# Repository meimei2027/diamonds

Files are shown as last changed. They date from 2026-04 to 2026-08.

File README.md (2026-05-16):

### Experimental Design
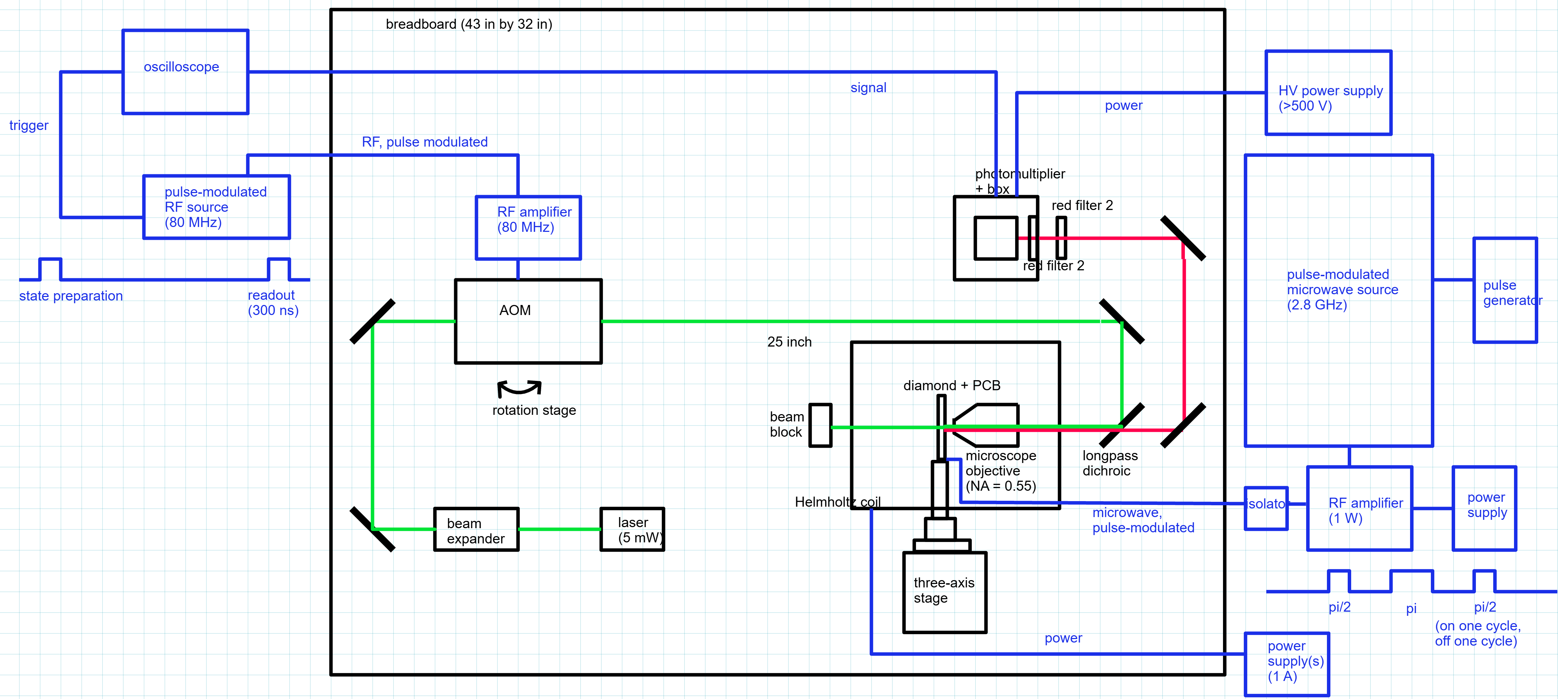
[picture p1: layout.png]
layout

### NV diamond spectrum
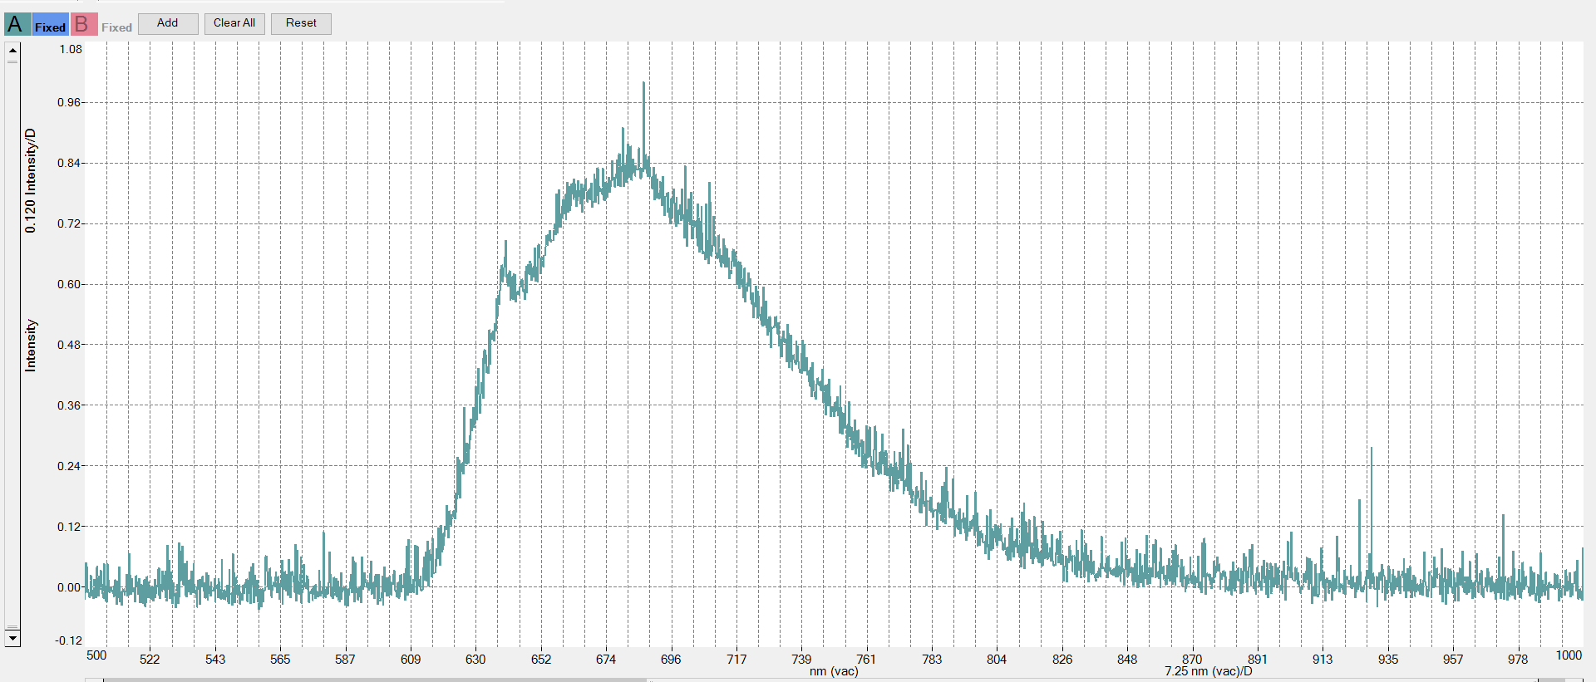
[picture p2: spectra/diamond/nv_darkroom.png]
spectra

Figure obtained using a Thorlabs CCS200 spectrometer with 10 second integration time. 
A fluorescence signal was obtained by directing the 532nm laser onto the diamond, then using a FGL630M longpass filter to isolate the red fluorescence.

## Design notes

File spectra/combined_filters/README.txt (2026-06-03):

All data was collected using a 1Hz on off pulse on a 532nm laser, which was focused onto the diamond using a microscope objective, then filtered out by a DMLP550 dichroric mirror as well. The spectra was taken using a CCS200 thorlabs optical spectrometer, with the lights off.

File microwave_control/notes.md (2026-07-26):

# Instrument gotchas

Quick reference for things that aren't obvious from the driver code alone.
See `CLAUDE.md` for the full investigation history behind each of these.

## HP8673H signal generator

- **Pre-SCPI, mnemonic ASCII commands** (e.g. `FR3000000000HZ`), not SCPI
  strings. Full command table is Table 3-7 in the HP 8673C/D manual (same
  codes across the whole 8673A/B/C/D/E/G/H family).
- **Frequency resolution is 1 kHz** between 2-4 GHz on our unit (matches the
  manual's spec table). Anything finer gets silently floored.
- **Sweep-start settling**: the first point of any sweep involves a large
  jump from wherever the generator was previously sitting. AUTO PEAK
  re-leveling triggers automatically on frequency changes >50 MHz and takes
  much longer to settle than normal step-to-step timing. Without an extra
  delay after that initial jump, the first few points of a sweep read
  anomalously low -- easy to mistake for a real resonance dip, especially
  since it appears at whatever frequency the sweep happens to start at.
  `frequency_sweep()` handles this via `initial_settle_s` (default 1.0 s,
  applied once before the per-step loop begins) -- don't set it to 0 unless
  you really know what you're doing.
- **GPIB bus number isn't stable.** Has shown up as both `GPIB0::19::INSTR`
  and `GPIB1::19::INSTR` depending on adapter enumeration order. Always
  `pyvisa.ResourceManager().list_resources()` before assuming an address.

## E4403B spectrum analyzer

- **Trace averaging** is `AVER:STATE ON` + `AVER:COUNT n`, not
  `DISP:WIND:TRAC1:MODE AVER` (undefined header on this firmware).
  `TRAC1:MODE` only accepts `WRITE|MAXHOLD|MINHOLD|VIEW|BLANK`.
- **`TRAC1:MODE BLANK` poisons subsequent reads**: `TRACE:DATA?` returns a
  flat sentinel (`400.0` everywhere) until you set the mode back to
  `WRITE`. Looks like a driver bug, is actually leftover instrument state.
- **Amplitude calibration can genuinely drift out of spec.** We hit a real
  fault where readings were 20-37 dB too high, worse at some frequencies
  than others. All of the instrument's own settings (attenuation, preamp,
  units, offset) checked out normal -- it was a real internal cal fault, not
  a settings mistake. **Fix: front panel Align Now -> RF (not Align Now ->
  All), with a cable connected to the input.** After a real cal fault, don't
  trust *any* absolute dBm reading until this has been done and reverified
  with a known source.
- **Even when calibration is healthy, expect a small residual offset** from
  ordinary cable loss (we consistently see ~-4.4 to -4.5 dB direct
  generator-to-analyzer). This is normal, not a fault -- re-measure if the
  cable changes.
- **Noise floor is RBW/attenuation dependent, and auto-RBW isn't always what
  you expect.** Measured ~-64.3 dBm median at 1 MHz RBW / 10 dB attenuation,
  but the analyzer's auto-coupling picked 3 MHz RBW for the same 500 MHz
  span on one occasion, giving a very different-looking floor. Set `BAND`
  explicitly if you need a result comparable to a previous measurement.
- **"Query UNTERMINATED" / frozen-looking display**: caused by an
  exploratory SCPI query that isn't valid on this firmware timing out on
  the controller side without ever reading the response, leaving the
  instrument's output queue in a pending state. Fix: drain any stale
  response (`inst.read()` in a loop until it raises), then `inst.clear()`
  (GPIB device clear) followed by `*CLS`.

## General

- **Two GPIB-USB adapters share a USB hub**, causing intermittent
  `VI_ERROR_CONN_LOST`. `visa_retry.py`'s `call_with_reconnect()` retries
  automatically (up to 3x) and is already wired into both driver classes'
  `write`/`query`/`get_trace` -- but a hard crash with this error mid-sweep
  is usually just this, and a plain retry of the same sweep works.
- **Always verify a new physical setup before trusting a measurement.**
  Sweep the generator's power over a wide range at a fixed frequency and
  confirm the analyzer's reading actually tracks it, then confirm it drops
  further with RF off. A disconnected/floating analyzer input on this
  E4403B reads a flat, power-independent, RF-state-independent level
  (~-45 to -48 dBm across 2-3 GHz) that looks deceptively like a real, if
  boring, signal.
- **Step size for finding an unknown resonance should track its FWHM, not
  be a fixed default.** Rule of thumb: step <= FWHM/5 to reliably identify
  a dip and get a rough shape; step <= FWHM/2 only guarantees detection,
  not an accurate depth. `resonance_sweep.py`'s default coarse step
  (6.7 MHz) assumes Q ~75 -- retune it if you have reason to expect a much
  higher-Q (narrower) resonance.
- **A coupler's directivity sets a hard floor on reflection measurements.**
  Our ZABDC20-322H-S+ has ~13 dB directivity in this band -- if whatever
  you're measuring reflects less than that relative to a matched load, you
  won't be able to tell it apart from the coupler's own leakage.

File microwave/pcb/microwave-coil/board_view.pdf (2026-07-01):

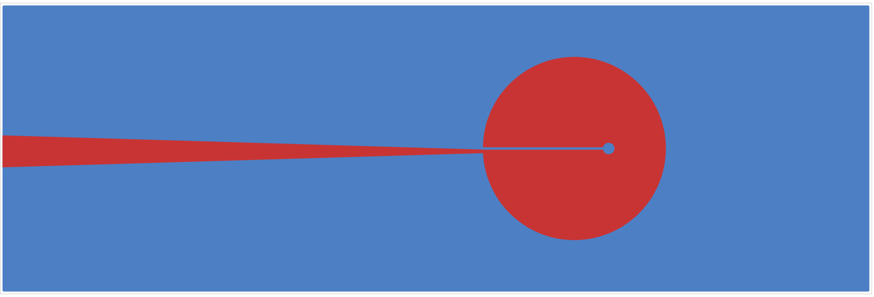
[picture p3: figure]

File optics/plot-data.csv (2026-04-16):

x | y
3.199253183930214e-7 | 0.04125478376005761
3.4184309641687807e-7 | 0.0519011615553862
3.5778330552594773e-7 | 0.06787075363134606
3.68742194537876e-7 | 0.08650190208168791
3.806974083763627e-7 | 0.10114071597045689
3.936487950235825e-7 | 0.12642585688862082
4.056040088620691e-7 | 0.1450570561048964
4.1556664905635175e-7 | 0.16102664818085627
4.2552928925063434e-7 | 0.17699618949088242
4.374844270802084e-7 | 0.1929657815668423
4.47447067274491e-7 | 0.21026615182999314
4.6239102756591485e-7 | 0.2302281292334595
4.76338739039693e-7 | 0.25019010663692604
4.88293876869267e-7 | 0.2688213058532015
4.96264019428258e-7 | 0.2821292907888458
5.11207979719682e-7 | 0.2954372757244902
5.211706199139646e-7 | 0.31539925312795664
5.34122082570097e-7 | 0.3326996233911075
5.510585404968124e-7 | 0.34866921546706736
5.620174295087406e-7 | 0.36064642221552073
5.749688921648731e-7 | 0.373954407151165
5.919053500915884e-7 | 0.3952471627418224
6.058530615653664e-7 | 0.40456276234996014
6.168119505772948e-7 | 0.421863132613111
6.287671644157816e-7 | 0.4311787322212487
6.367372309658602e-7 | 0.43916350287626177
6.466998711601426e-7 | 0.44581749534408394
6.556662625367795e-7 | 0.4551330949522217
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

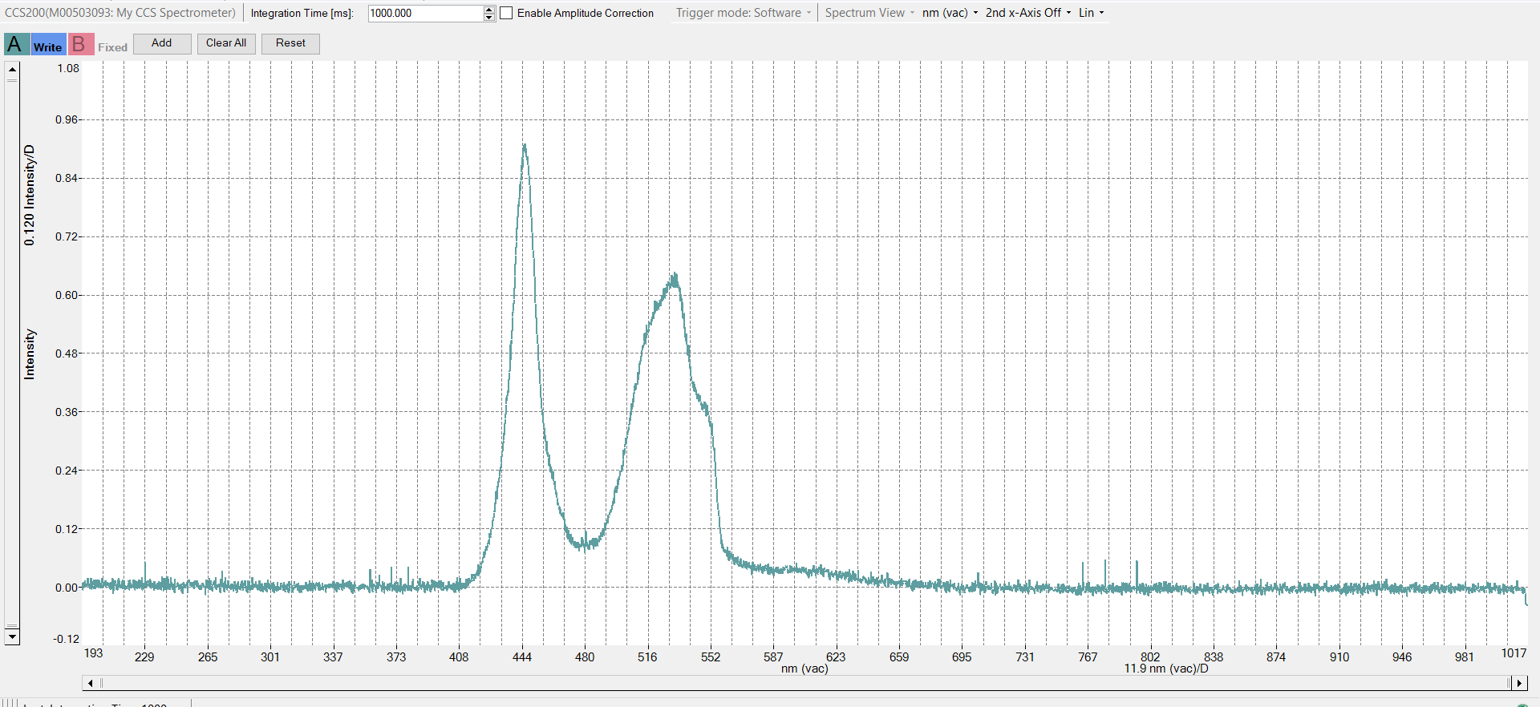
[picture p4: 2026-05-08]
spectra/filters/darkroom_white_light_DMLP550.png

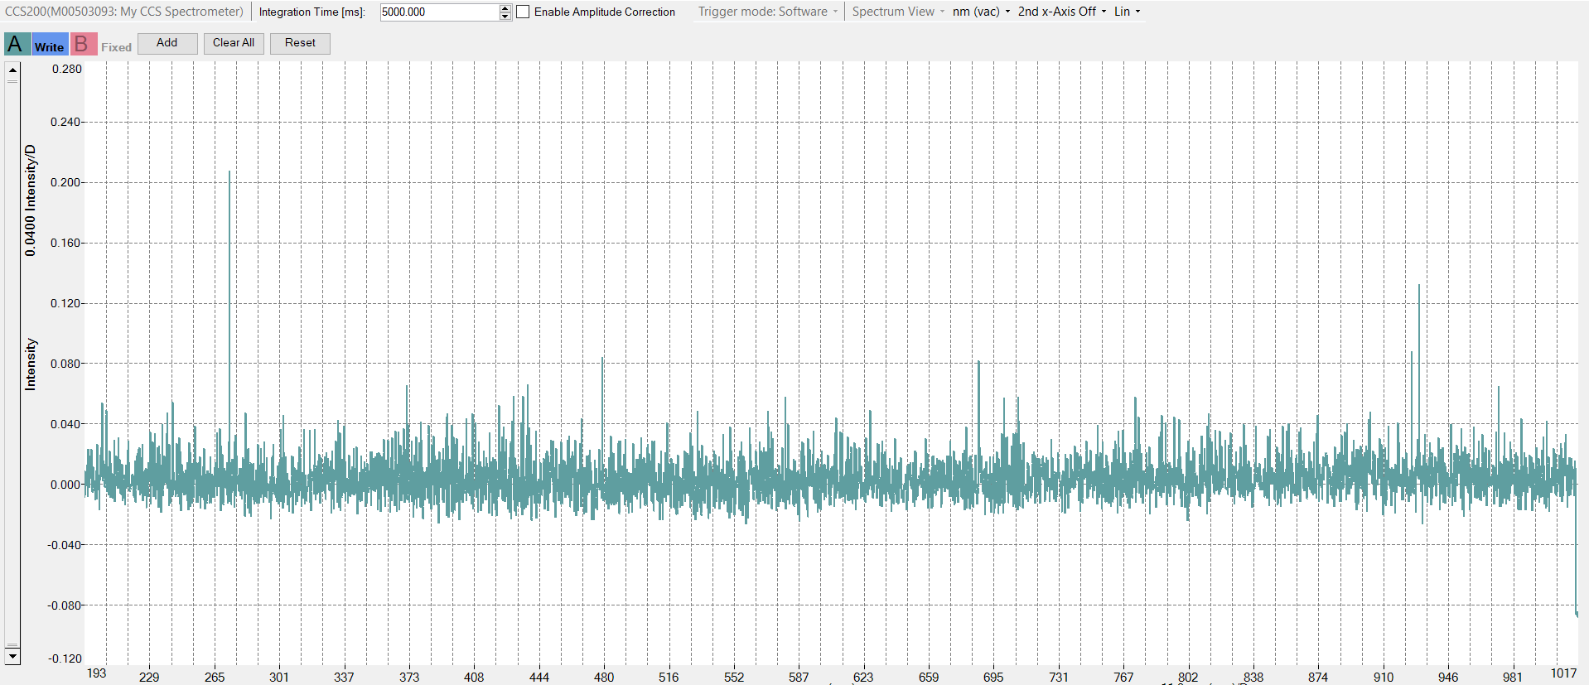
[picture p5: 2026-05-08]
spectra/darkroom_background.png

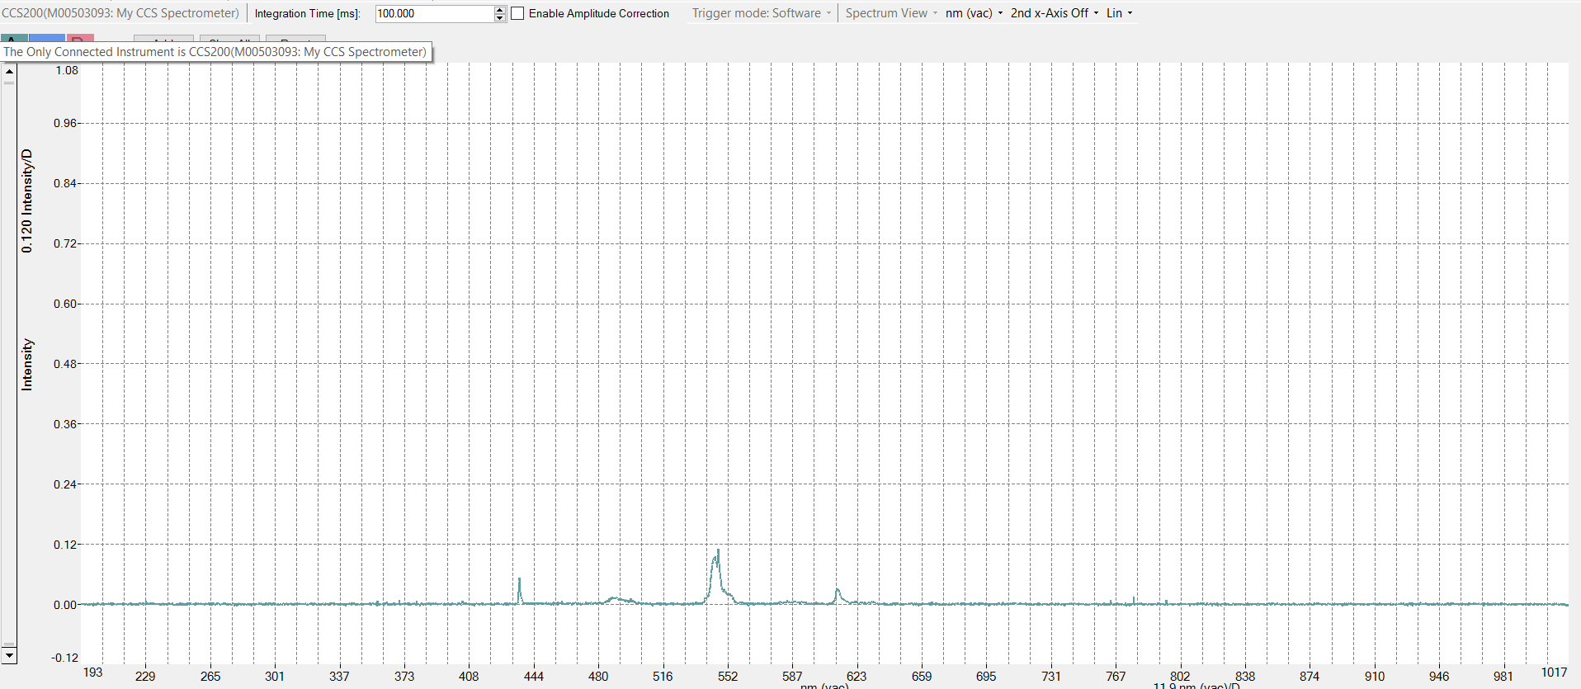
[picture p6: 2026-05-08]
spectra/filters/laser_DMLP550.png

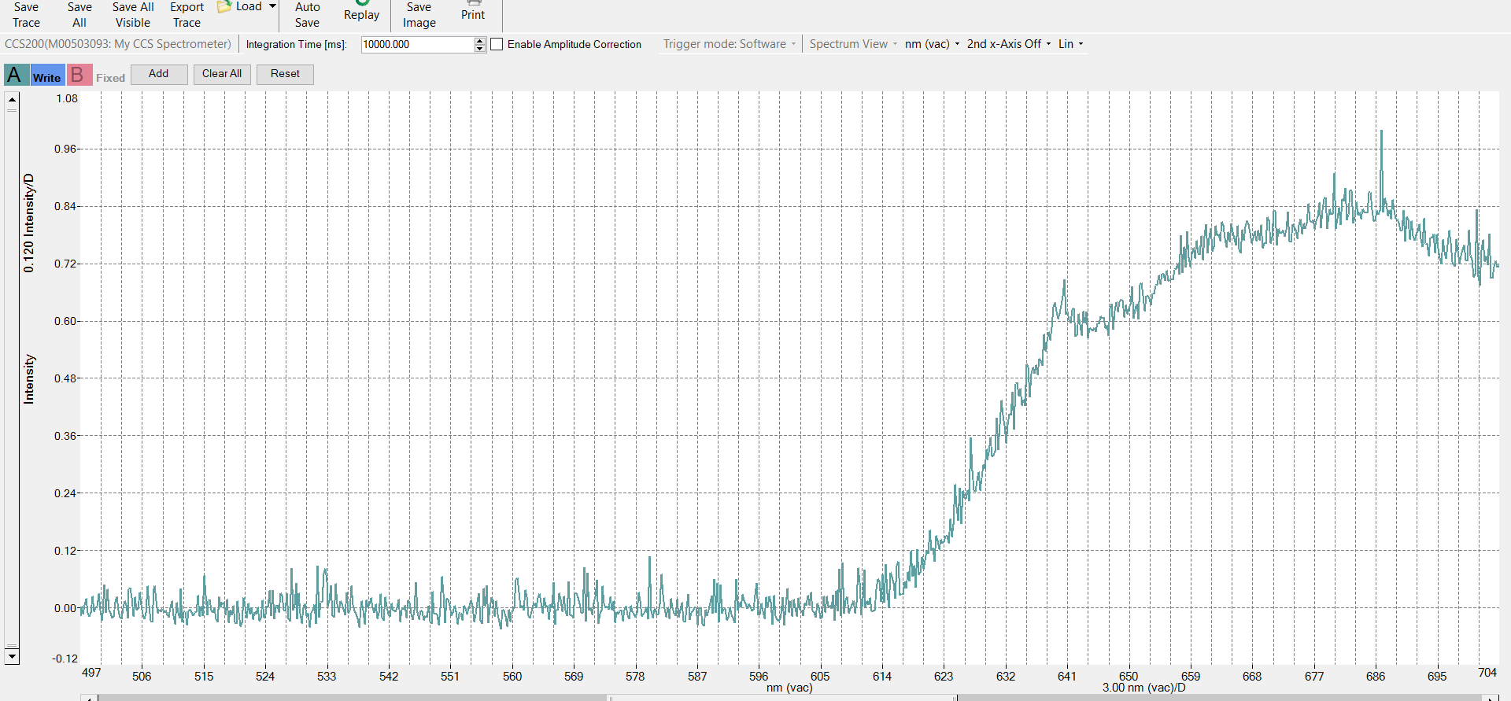
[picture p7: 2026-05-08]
spectra/diamond/nv_darkroom_3.png

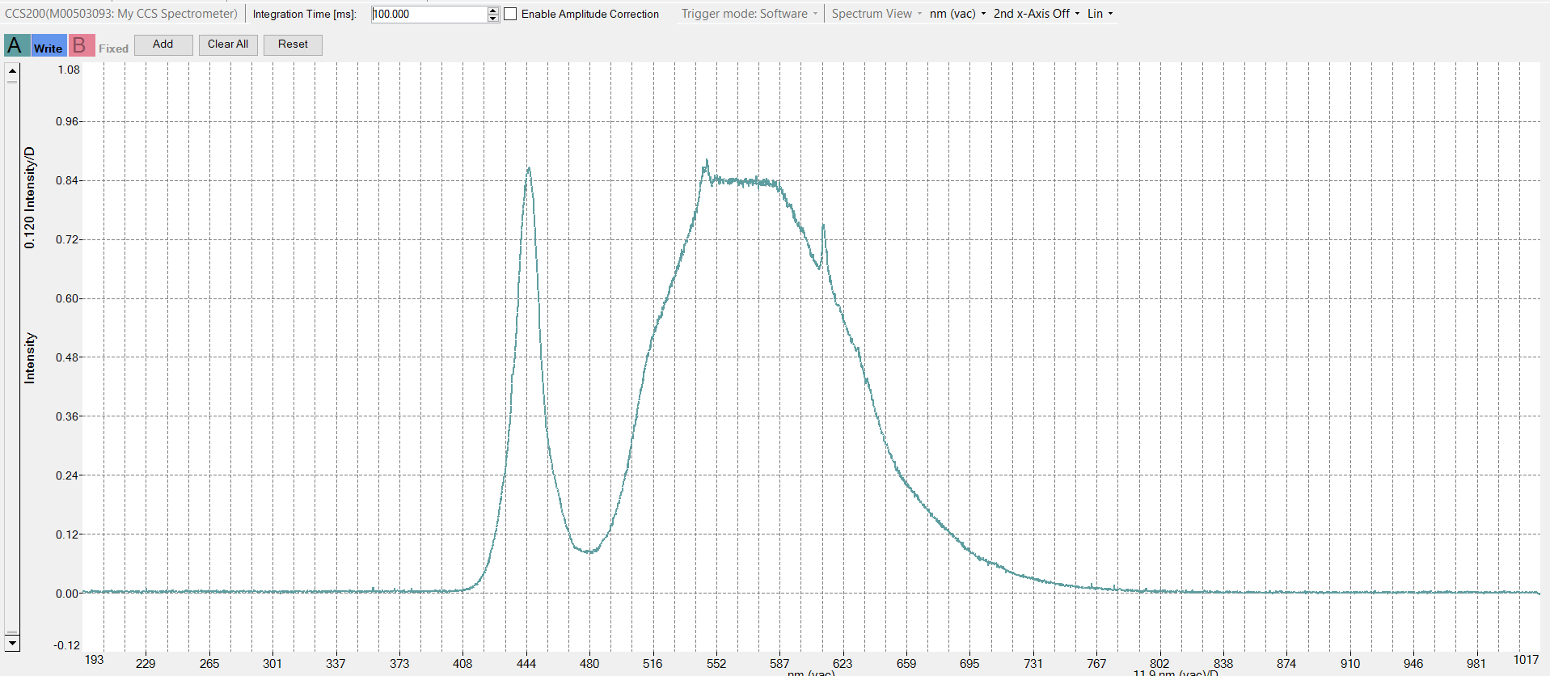
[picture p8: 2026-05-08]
spectra/filters/white_light_no_filter.png

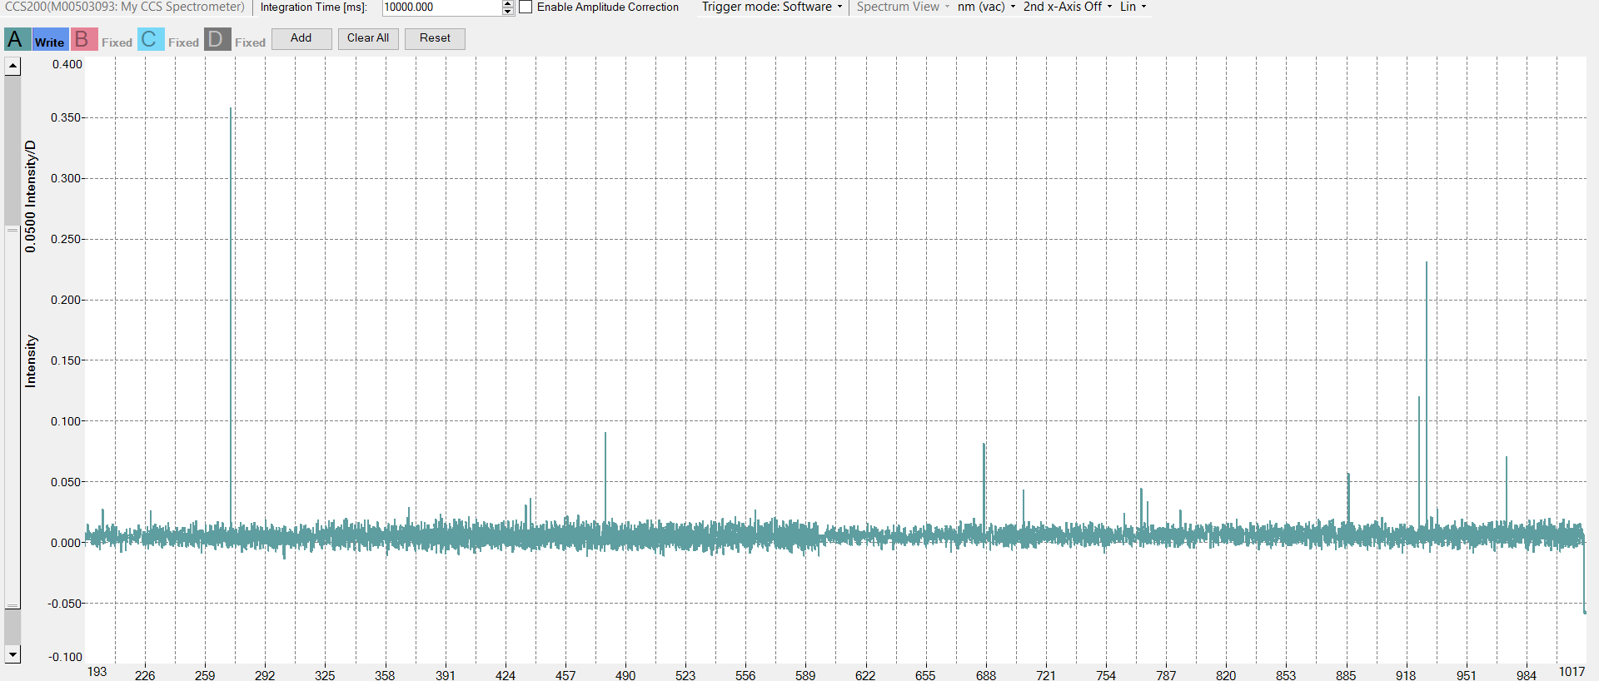
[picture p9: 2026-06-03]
spectra/combined_filters/capped_optical_cable.png

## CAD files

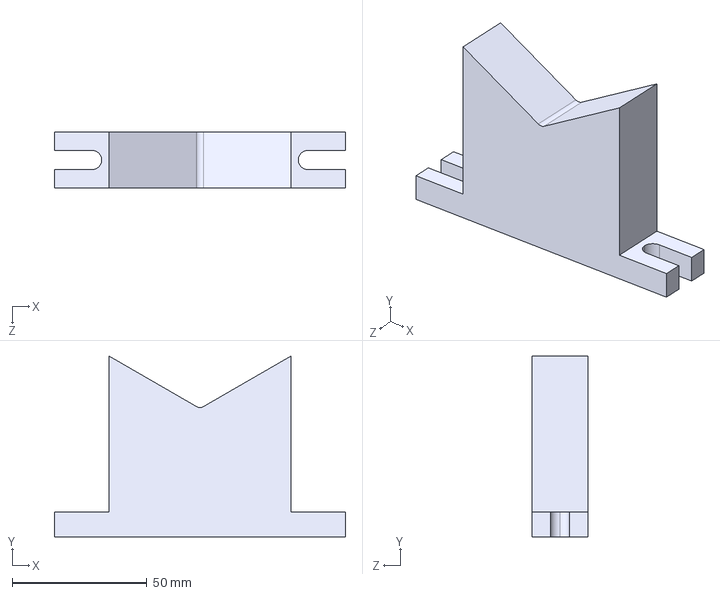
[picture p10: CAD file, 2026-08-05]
drawings/coil-holder.STEP
108.1 x 67.1 x 20.8 mm

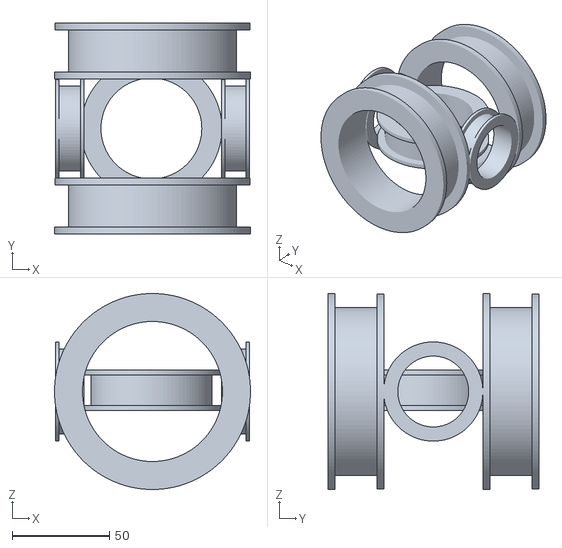
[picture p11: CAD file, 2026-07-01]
presentation_plot/Helmholtz Coils.stl
100.8 x 108.6 x 100.8

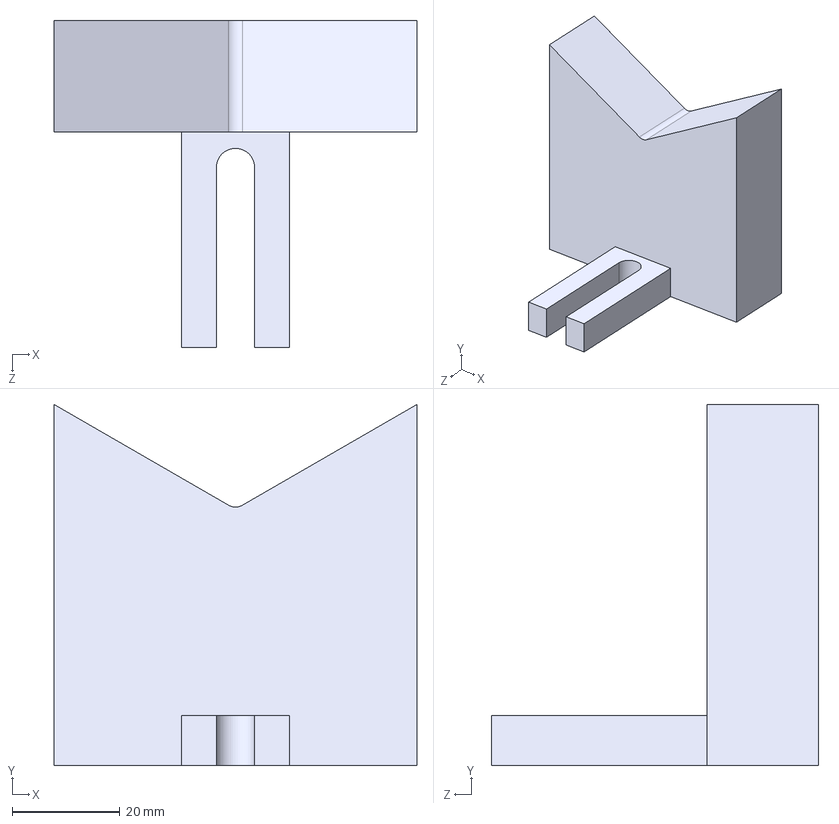
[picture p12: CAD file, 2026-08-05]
drawings/coil-holder-2.STEP
67.5 x 67.1 x 60.8 mm

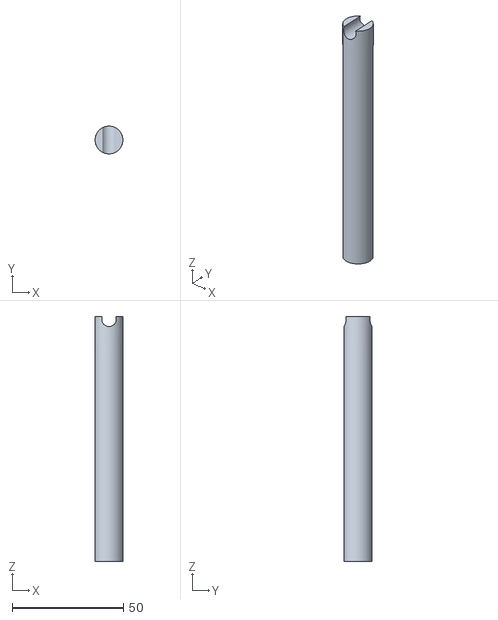
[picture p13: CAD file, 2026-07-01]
presentation_plot/CopperTubeMount.stl
12.5 x 12.5 x 110.0

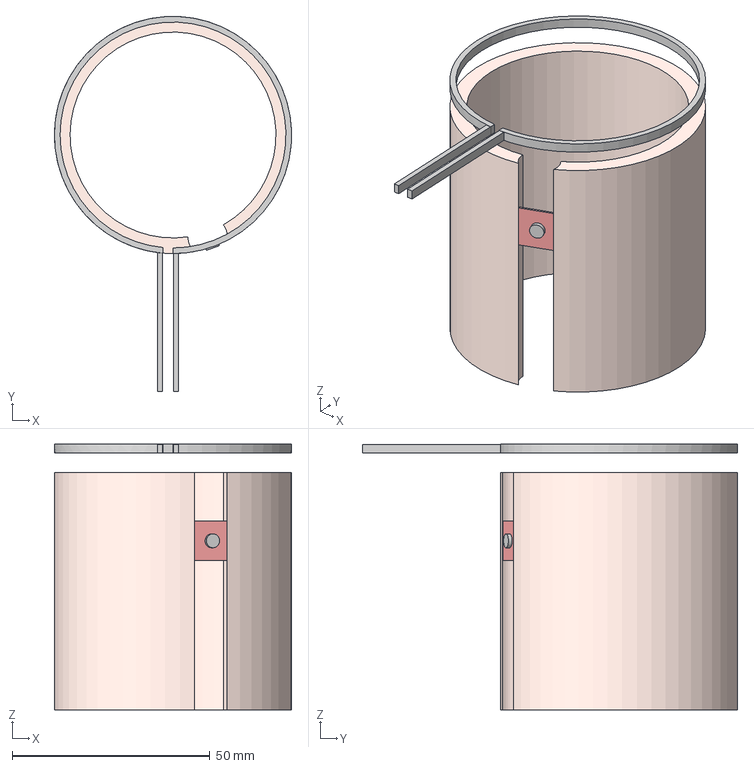
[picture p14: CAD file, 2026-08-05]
drawings/LoopGapResonator.step
60.0 x 94.9 x 67.2 mm

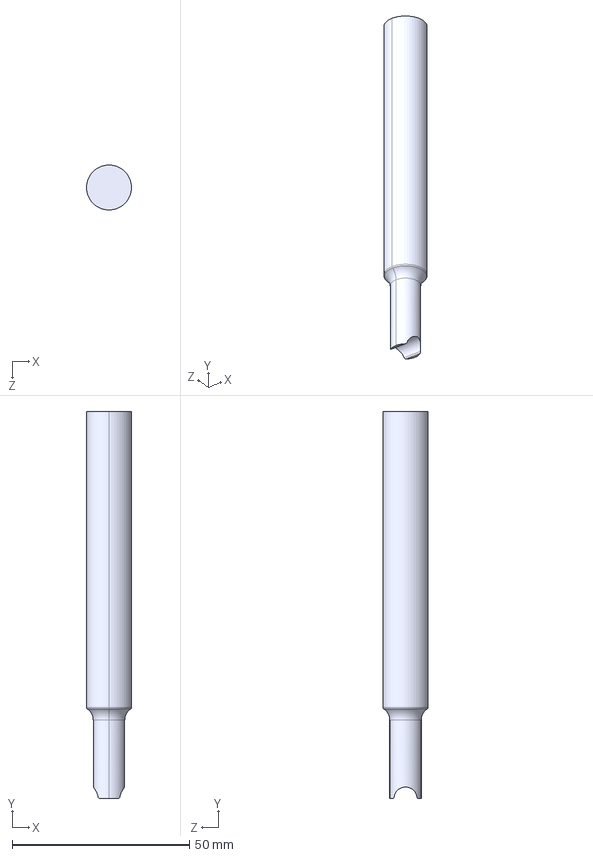
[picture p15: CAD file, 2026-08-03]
drawings/copper-tube-mount.STEP
12.7 x 109.2 x 12.7 mm

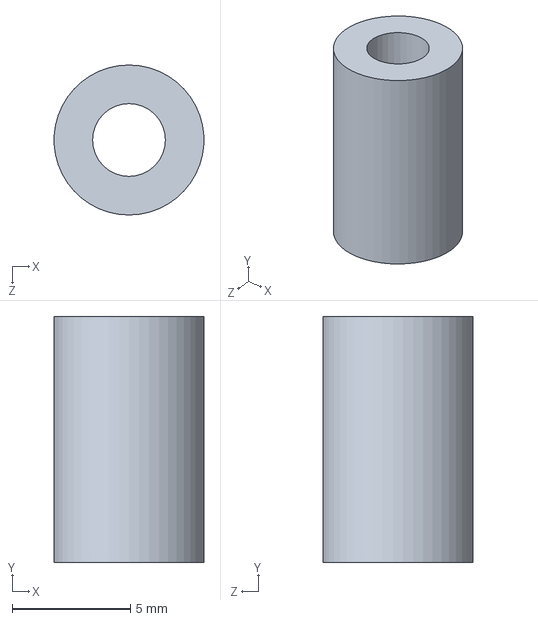
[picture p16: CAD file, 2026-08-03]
drawings/copper-tube.SLDPRT
6.34 x 10.4 x 6.35 mm

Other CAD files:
drawings/coil-holder-2.SLDPRT
drawings/coil-holder.SLDPRT

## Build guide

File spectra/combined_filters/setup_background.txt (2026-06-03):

1.933779755e+02,-1.095455792e-02
1.935834351e+02,-2.785268798e-02
1.937889099e+02,-4.011977580e-04
1.939943848e+02,-1.736309379e-02
1.941998901e+02,-5.757586099e-03
1.944053955e+02,-1.669354551e-02
1.946109161e+02,1.436075382e-02
1.948164520e+02,-9.009678848e-03
1.950220032e+02,1.002462953e-02
1.952275696e+02,-2.109343745e-02
1.954331360e+02,4.104704782e-02
1.956387177e+02,4.694544896e-02
1.958443298e+02,2.548801340e-02
1.960499420e+02,-2.000940591e-02
1.962555695e+02,1.598680019e-02
1.964611969e+02,4.598895088e-02
1.966668549e+02,2.436412731e-03
1.968725128e+02,3.718917072e-02
1.970782013e+02,5.784155801e-03
1.972838898e+02,4.873091355e-02
1.974895935e+02,1.228834130e-02
1.976953125e+02,2.816620655e-02
1.979010315e+02,-2.125285380e-02
1.981067810e+02,-1.886160858e-02
1.983125305e+02,1.503030211e-02
1.985182953e+02,2.612567879e-02
1.987240906e+02,-1.513126586e-02
1.989298706e+02,-1.867030933e-02
1.991356812e+02,-1.870219223e-02
1.993415070e+02,-1.694861241e-02
1.995473328e+02,-2.590780891e-02
1.997531891e+02,-1.439795084e-02
1.999590454e+02,-1.541821565e-02
2.001649170e+02,1.798747573e-03
2.003708038e+02,-2.517449483e-02
2.005766907e+02,5.153664201e-02
2.007826080e+02,1.930266060e-02
2.009885254e+02,-1.752251014e-02
2.011944733e+02,-1.436606795e-02
2.014004211e+02,-3.366341349e-03
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

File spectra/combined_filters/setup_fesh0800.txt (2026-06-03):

1.933779755e+02,-1.910143066e-03
1.935834351e+02,-2.361193672e-02
1.937889099e+02,7.752933539e-03
1.939943848e+02,-2.162153460e-02
1.941998901e+02,4.815486682e-05
1.944053955e+02,-4.446299281e-03
1.946109161e+02,1.420568582e-02
1.948164520e+02,2.134865616e-03
1.950220032e+02,1.414147858e-02
1.952275696e+02,-1.812228188e-02
1.954331360e+02,2.377245203e-02
1.956387177e+02,3.850784153e-02
1.958443298e+02,2.027319930e-02
1.960499420e+02,-1.394885965e-02
1.962555695e+02,1.369203348e-02
1.964611969e+02,3.260084614e-02
1.966668549e+02,6.789836101e-03
1.968725128e+02,2.903738432e-02
1.970782013e+02,5.248880479e-03
1.972838898e+02,3.610009700e-02
1.974895935e+02,1.648501493e-02
1.976953125e+02,1.706287451e-02
1.979010315e+02,-1.812228188e-02
1.981067810e+02,-5.987254903e-03
1.983125305e+02,1.658132486e-02
1.985182953e+02,-5.826738663e-03
1.987240906e+02,-3.643718082e-03
1.989298706e+02,-1.487985346e-02
1.991356812e+02,-1.446251106e-02
1.993415070e+02,-2.648517722e-03
1.995473328e+02,-2.367614210e-02
1.997531891e+02,-1.561822835e-02
1.999590454e+02,-1.462302729e-02
2.001649170e+02,8.298688568e-03
2.003708038e+02,-2.107577957e-02
2.005766907e+02,4.085137695e-02
2.007826080e+02,1.677394472e-02
2.009885254e+02,-6.500906777e-03
2.011944733e+02,-3.996853717e-03
2.014004211e+02,-2.070659306e-03
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

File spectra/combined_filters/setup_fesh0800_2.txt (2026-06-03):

1.933779755e+02,4.438553005e-03
1.935834351e+02,-1.567346975e-02
1.937889099e+02,8.513111621e-03
1.939943848e+02,-1.544529479e-02
1.941998901e+02,5.286061205e-03
1.944053955e+02,-1.901460928e-04
1.946109161e+02,1.323960070e-02
1.948164520e+02,3.004308091e-03
1.950220032e+02,1.597770490e-02
1.952275696e+02,-1.225084066e-02
1.954331360e+02,2.295334823e-02
1.956387177e+02,3.475327045e-02
1.958443298e+02,1.780310646e-02
1.960499420e+02,-6.546458229e-03
1.962555695e+02,1.118602231e-02
1.964611969e+02,2.944004722e-02
1.966668549e+02,6.752902642e-03
1.968725128e+02,2.653896064e-02
1.970782013e+02,4.797114059e-03
1.972838898e+02,3.162401170e-02
1.974895935e+02,1.871580817e-02
1.976953125e+02,1.571693271e-02
1.979010315e+02,-7.882913575e-03
1.981067810e+02,-1.396215521e-03
1.983125305e+02,1.284844242e-02
1.985182953e+02,-5.829335656e-03
1.987240906e+02,-2.634881530e-03
1.989298706e+02,-9.121579118e-03
1.991356812e+02,-7.687334437e-03
1.993415070e+02,7.062569057e-05
1.995473328e+02,-1.792262681e-02
1.997531891e+02,-8.795614354e-03
1.999590454e+02,-6.611651275e-03
2.001649170e+02,6.296551786e-03
2.003708038e+02,-1.492375135e-02
2.005766907e+02,3.736098856e-02
2.007826080e+02,1.715117693e-02
2.009885254e+02,-1.754776691e-03
2.011944733e+02,-3.352003871e-03
2.014004211e+02,5.921692355e-04
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

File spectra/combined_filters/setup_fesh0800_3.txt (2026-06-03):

1.933779755e+02,4.531820770e-03
1.935834351e+02,-1.525821630e-02
1.937889099e+02,9.259259328e-03
1.939943848e+02,-1.424752176e-02
1.941998901e+02,4.140584264e-03
1.944053955e+02,-6.683620159e-03
1.946109161e+02,1.339984313e-02
1.948164520e+02,5.444705486e-03
1.950220032e+02,1.760563441e-02
1.952275696e+02,-1.216092892e-02
1.954331360e+02,1.806207560e-02
1.956387177e+02,3.713484481e-02
1.958443298e+02,2.239827812e-02
1.960499420e+02,-8.281168528e-03
1.962555695e+02,1.476917043e-02
1.964611969e+02,2.813641168e-02
1.966668549e+02,6.879238412e-03
1.968725128e+02,2.096374519e-02
1.970782013e+02,5.933750421e-03
1.972838898e+02,2.869066224e-02
1.974895935e+02,1.633411646e-02
1.976953125e+02,1.874673925e-02
1.979010315e+02,-9.846113622e-03
1.981067810e+02,-9.780908003e-04
1.983125305e+02,1.463875826e-02
1.985182953e+02,-5.868544802e-03
1.987240906e+02,1.695357380e-03
1.989298706e+02,-6.716223434e-03
1.991356812e+02,-6.422795821e-03
1.993415070e+02,-4.368805327e-03
1.995473328e+02,-1.718179509e-02
1.997531891e+02,-1.066118944e-02
1.999590454e+02,-8.215961978e-03
2.001649170e+02,4.597026389e-03
2.003708038e+02,-1.571465842e-02
2.005766907e+02,3.403756022e-02
2.007826080e+02,1.926838793e-02
2.009885254e+02,-3.521126695e-03
2.011944733e+02,-6.846635370e-04
2.014004211e+02,5.607720464e-03
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

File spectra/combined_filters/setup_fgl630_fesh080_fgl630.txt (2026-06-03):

1.933779755e+02,3.769290168e-03
1.935834351e+02,-1.209912356e-02
1.937889099e+02,1.004511770e-02
1.939943848e+02,-1.174143329e-02
1.941998901e+02,3.801807528e-03
1.944053955e+02,-3.482054453e-03
1.946109161e+02,1.365453098e-02
1.948164520e+02,6.598290056e-03
1.950220032e+02,2.028804831e-02
1.952275696e+02,-9.270123206e-03
1.954331360e+02,2.071077190e-02
1.956387177e+02,3.085615113e-02
1.958443298e+02,1.921498030e-02
1.960499420e+02,-4.587640520e-03
1.962555695e+02,1.131329034e-02
1.964611969e+02,2.750687674e-02
1.966668549e+02,3.216497134e-03
1.968725128e+02,2.461284213e-02
1.970782013e+02,5.525221117e-03
1.972838898e+02,2.770197950e-02
1.974895935e+02,1.713387668e-02
1.976953125e+02,1.560556609e-02
1.979010315e+02,-8.587261662e-03
1.981067810e+02,-2.408985514e-03
1.983125305e+02,1.615835913e-02
1.985182953e+02,9.037083015e-03
1.987240906e+02,-1.205847715e-03
1.989298706e+02,-5.953365006e-03
1.991356812e+02,-1.014808938e-02
1.993415070e+02,-8.481580298e-04
1.995473328e+02,-1.515574381e-02
1.997531891e+02,-7.839364931e-03
1.999590454e+02,-6.148468237e-03
2.001649170e+02,4.126979969e-03
2.003708038e+02,-1.209912356e-02
2.005766907e+02,3.579877317e-02
2.007826080e+02,1.401222125e-02
2.009885254e+02,-3.774709767e-03
2.011944733e+02,-2.961778780e-03
2.014004211e+02,1.753221266e-03
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

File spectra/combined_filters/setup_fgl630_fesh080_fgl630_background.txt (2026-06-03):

1.933779755e+02,3.246612148e-03
1.935834351e+02,-1.291044150e-02
1.937889099e+02,7.839645259e-03
1.939943848e+02,-1.115140691e-02
1.941998901e+02,8.556288667e-03
1.944053955e+02,-4.669041082e-04
1.946109161e+02,7.676771842e-03
1.948164520e+02,1.194405835e-03
1.950220032e+02,1.536440197e-02
1.952275696e+02,-1.356193516e-02
1.954331360e+02,2.266113646e-02
1.956387177e+02,3.644023463e-02
1.958443298e+02,2.083695307e-02
1.960499420e+02,-1.997915329e-03
1.962555695e+02,1.438716147e-02
1.964611969e+02,3.086996265e-02
1.966668549e+02,8.784311824e-03
1.968725128e+02,2.513681352e-02
1.970782013e+02,8.132818155e-03
1.972838898e+02,3.223809972e-02
1.974895935e+02,1.806810312e-02
1.976953125e+02,1.943624020e-02
1.979010315e+02,-8.936326951e-03
1.981067810e+02,-2.421386307e-03
1.983125305e+02,1.490835659e-02
1.985182953e+02,1.292129979e-02
1.987240906e+02,-1.053248765e-03
1.989298706e+02,-3.268328728e-03
1.991356812e+02,-7.828786969e-03
1.993415070e+02,-1.085823518e-03
1.995473328e+02,-1.607018709e-02
1.997531891e+02,-9.001476690e-03
1.999590454e+02,-7.503040135e-03
2.001649170e+02,3.995830659e-03
2.003708038e+02,-1.532096975e-02
2.005766907e+02,3.891591355e-02
2.007826080e+02,1.744918339e-02
2.009885254e+02,-4.343293840e-04
2.011944733e+02,5.429117300e-05
2.014004211e+02,1.096681692e-03
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

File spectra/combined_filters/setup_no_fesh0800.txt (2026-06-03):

1.933779755e+02,3.203026252e-03
1.935834351e+02,-1.394146401e-02
1.937889099e+02,9.113793261e-03
1.939943848e+02,-1.178615633e-02
1.941998901e+02,6.370674819e-03
1.944053955e+02,-1.695399522e-03
1.946109161e+02,1.159566175e-02
1.948164520e+02,4.835834727e-03
1.950220032e+02,1.469799876e-02
1.952275696e+02,-1.096975245e-02
1.954331360e+02,2.273141593e-02
1.956387177e+02,3.249561042e-02
1.958443298e+02,1.809423976e-02
1.960499420e+02,-8.128665388e-03
1.962555695e+02,1.460003015e-02
1.964611969e+02,2.694406360e-02
1.966668549e+02,4.803178366e-03
1.968725128e+02,2.586640976e-02
1.970782013e+02,8.003483526e-03
1.972838898e+02,3.154858202e-02
1.974895935e+02,1.985767297e-02
1.976953125e+02,1.786564663e-02
1.979010315e+02,-1.289646607e-02
1.981067810e+02,-2.609772375e-03
1.983125305e+02,1.678799279e-02
1.985182953e+02,5.946144462e-03
1.987240906e+02,1.635529916e-03
1.989298706e+02,-9.696161374e-03
1.991356812e+02,-8.161321282e-03
1.993415070e+02,-8.463390986e-04
1.995473328e+02,-1.528036688e-02
1.997531891e+02,-8.977726102e-03
1.999590454e+02,-1.002272312e-02
2.001649170e+02,5.260365084e-03
2.003708038e+02,-1.547630411e-02
2.005766907e+02,3.922278434e-02
2.007826080e+02,1.933517493e-02
2.009885254e+02,-1.630087267e-03
2.011944733e+02,1.668186043e-03
2.014004211e+02,2.288653282e-03
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

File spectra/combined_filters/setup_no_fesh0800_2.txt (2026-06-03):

1.933779755e+02,-8.401161176e-04
1.935834351e+02,-1.494751964e-02
1.937889099e+02,7.113710046e-03
1.939943848e+02,-1.671503671e-02
1.941998901e+02,1.745695772e-04
1.944053955e+02,-3.229537280e-03
1.946109161e+02,1.438016910e-02
1.948164520e+02,3.382285591e-03
1.950220032e+02,1.555851381e-02
1.952275696e+02,-1.579854637e-02
1.954331360e+02,2.495253831e-02
1.956387177e+02,3.493573517e-02
1.958443298e+02,1.588583179e-02
1.960499420e+02,-7.255548146e-03
1.962555695e+02,1.159796584e-02
1.964611969e+02,2.747288719e-02
1.966668549e+02,3.185894806e-03
1.968725128e+02,2.262858115e-02
1.970782013e+02,6.000829395e-03
1.972838898e+02,3.205533698e-02
1.974895935e+02,1.706417650e-02
1.976953125e+02,1.578763686e-02
1.979010315e+02,-1.232897677e-02
1.981067810e+02,-1.887533581e-03
1.983125305e+02,1.349641010e-02
1.985182953e+02,7.604687009e-03
1.987240906e+02,-2.607633127e-03
1.989298706e+02,-8.793942630e-03
1.991356812e+02,-1.193619519e-02
1.993415070e+02,-7.746525225e-04
1.995473328e+02,-1.799157634e-02
1.997531891e+02,-1.029960532e-02
1.999590454e+02,-1.111789979e-02
2.001649170e+02,7.179173641e-03
2.003708038e+02,-1.462020166e-02
2.005766907e+02,3.680144995e-02
2.007826080e+02,1.814432628e-02
2.009885254e+02,-2.640364924e-03
2.011944733e+02,1.091059821e-04
2.014004211e+02,-5.455299106e-05
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

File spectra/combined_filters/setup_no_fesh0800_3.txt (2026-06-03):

1.933779755e+02,3.791482188e-03
1.935834351e+02,-1.573560387e-02
1.937889099e+02,8.730494417e-03
1.939943848e+02,-1.472163573e-02
1.941998901e+02,7.193185855e-03
1.944053955e+02,-2.815672895e-03
1.946109161e+02,9.711754508e-03
1.948164520e+02,5.165247247e-03
1.950220032e+02,1.749642193e-02
1.952275696e+02,-1.230119262e-02
1.954331360e+02,2.446337231e-02
1.956387177e+02,3.358909860e-02
1.958443298e+02,1.965519600e-02
1.960499420e+02,-7.591141388e-03
1.962555695e+02,1.288449764e-02
1.964611969e+02,3.067802452e-02
1.966668549e+02,9.679046459e-03
1.968725128e+02,2.416899428e-02
1.970782013e+02,7.520272397e-03
1.972838898e+02,3.535536677e-02
1.974895935e+02,1.900102198e-02
1.976953125e+02,1.671141386e-02
1.979010315e+02,-1.197410561e-02
1.981067810e+02,-3.502555424e-03
1.983125305e+02,1.556660980e-02
1.985182953e+02,1.088926755e-02
1.987240906e+02,6.514480338e-04
1.989298706e+02,-5.857580807e-03
1.991356812e+02,-7.329471875e-03
1.993415070e+02,-3.625212994e-04
1.995473328e+02,-1.724020392e-02
1.997531891e+02,-1.007700153e-02
1.999590454e+02,-9.880749509e-03
2.001649170e+02,9.711754508e-03
2.003708038e+02,-1.406746171e-02
2.005766907e+02,4.022895917e-02
2.007826080e+02,1.772538386e-02
2.009885254e+02,-5.914820940e-04
2.011944733e+02,4.151277710e-03
2.014004211e+02,2.581260633e-03
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

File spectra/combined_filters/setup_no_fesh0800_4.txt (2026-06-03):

1.933779755e+02,6.105266046e-03
1.935834351e+02,-3.079877002e-03
1.937889099e+02,7.195028476e-03
1.939943848e+02,8.004566655e-03
1.941998901e+02,4.112557042e-03
1.944053955e+02,7.809966337e-04
1.946109161e+02,3.489835421e-03
1.948164520e+02,7.911158726e-03
1.950220032e+02,1.410723757e-02
1.952275696e+02,1.746215043e-03
1.954331360e+02,2.898250008e-03
1.956387177e+02,2.867113799e-03
1.958443298e+02,8.129110560e-03
1.960499420e+02,1.777351135e-03
1.962555695e+02,7.809966337e-04
1.964611969e+02,6.416626740e-03
1.966668549e+02,6.354354322e-03
1.968725128e+02,4.237101413e-03
1.970782013e+02,-9.626237443e-04
1.972838898e+02,3.988012671e-03
1.974895935e+02,7.724341936e-03
1.976953125e+02,3.303018864e-03
1.979010315e+02,1.279173885e-03
1.981067810e+02,-3.640326438e-03
1.983125305e+02,9.343418293e-03
1.985182953e+02,-5.889908061e-04
1.987240906e+02,4.922094755e-03
1.989298706e+02,6.105266046e-03
1.991356812e+02,3.863468301e-03
1.993415070e+02,-7.135351188e-04
1.995473328e+02,-2.083522500e-03
1.997531891e+02,7.412981242e-03
1.999590454e+02,1.055772509e-02
2.001649170e+02,-5.290538538e-03
2.003708038e+02,-5.267186207e-04
2.005766907e+02,8.160247467e-03
2.007826080e+02,9.374554269e-03
2.009885254e+02,-4.948041867e-03
2.011944733e+02,2.026439644e-03
2.014004211e+02,1.276838686e-02
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

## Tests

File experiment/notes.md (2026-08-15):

# Instrument gotchas

Quick reference for things that aren't obvious from the driver code alone.
See `CLAUDE.md` for the full investigation history behind each of these.

## HP8673H signal generator

- **Pre-SCPI, mnemonic ASCII commands** (e.g. `FR3000000000HZ`), not SCPI
  strings. Full command table is Table 3-7 in the HP 8673C/D manual (same
  codes across the whole 8673A/B/C/D/E/G/H family).
- **Frequency resolution is 1 kHz** between 2-4 GHz on our unit (matches the
  manual's spec table). Anything finer gets silently floored.
- **Sweep-start settling**: the first point of any sweep involves a large
  jump from wherever the generator was previously sitting. AUTO PEAK
  re-leveling triggers automatically on frequency changes >50 MHz and takes
  much longer to settle than normal step-to-step timing. Without an extra
  delay after that initial jump, the first few points of a sweep read
  anomalously low -- easy to mistake for a real resonance dip, especially
  since it appears at whatever frequency the sweep happens to start at.
  `frequency_sweep()` handles this via `initial_settle_s` (default 1.0 s,
  applied once before the per-step loop begins) -- don't set it to 0 unless
  you really know what you're doing.
- **GPIB bus number isn't stable.** Has shown up as both `GPIB0::19::INSTR`
  and `GPIB1::19::INSTR` depending on adapter enumeration order. Always
  `pyvisa.ResourceManager().list_resources()` before assuming an address.
- **`frequency_sweep()` with `settle_s=0` (the old default) produces a false,
  >13 dB deep "dip" of >13 dB at specific frequencies (we hit it at ~2.10 GHz
  and ~2.30 GHz) that looks exactly like a real resonance or a generator
  hardware defect -- it's neither.** First suspected this was a genuine
  defect in the generator itself: reproduced it with the generator connected
  directly into the E4403B, nothing else in the chain (ruling out the
  resonator and the amplifier). But holding the generator at those exact
  frequencies directly (bypassing the sweep's per-step logic) showed no dip
  at all, at any settle time up to 2s -- so it isn't a permanent property of
  the generator's steady-state output either. Root cause: `frequency_sweep()`
  does `if settle_s: time.sleep(settle_s)` -- with `settle_s=0` that's falsy
  and the sleep is skipped entirely, so the analyzer's `INIT:IMM` fires
  essentially immediately after the frequency-change command is sent, racing
  the GPIB bus/generator before it's finished processing that command.
  Confirmed by reproducing the exact sweep grid with `settle_s=0` (dip
  reappears every time, sometimes even deeper) vs `settle_s=0.02`-`0.3`
  (completely gone, at every value tested). **Fixed**: `frequency_sweep()`'s
  default `settle_s` is now `0.05` (was `0.0`) -- never pass `settle_s=0`
  intentionally. `coarse_sweep()` (and therefore `resonance_sweep()`'s coarse
  stage) never passed `settle_s` explicitly, so it silently inherited the old
  buggy default -- this is almost certainly what produced an earlier spurious
  result of `f0 ~= 2.09 GHz, Q ~= 5227` that had nothing to do with the real
  resonator. `fine_sweep()`'s existing `settle_s=0.15` was always safe.
- **Interlock operating point, as configured in `hp8673h.py`'s CLI defaults:**
  `--freq-hz 2.68725e9` (measured f0, amplifier in the path, -40 dBm drive --
  reproduced across 3 independent sweeps within ~1 MHz), `--power-dbm 0.0`
  (drives the amplifier to its measured max output, ~20 dBm -- see the
  amplifier gain/max-output notes above), `--threshold-dbm -10.0`.
  Reasoning for the threshold: at 0 dBm drive / ~20 dBm amplifier output,
  assuming ~15 dB return loss for a "detuned but still connected" resonator,
  reflected power (coupled at the established 20 dB coupling factor) is
  expected in the -15 to -25 dBm range during normal operation; -10 dBm
  gives 5-10 dB of margin above that before tripping. For a full-disconnect
  fault (near-total reflection), the coupled reading would be closer to
  0 dBm -- comfortably above the -10 dBm threshold, so it still catches that
  case with margin.
  **Open safety question, not resolved:** in that same full-disconnect fault,
  after the isolator's tested ~7 dB isolation (tested against an open),
  ~13 dBm would reach the HP8347A amplifier's output stage. The HP8347A
  datasheet (Keysight literature 5091-0370E) does not publish a maximum
  safe reflected/reverse power rating for the output port -- "Output SWR"
  in that datasheet describes the amplifier's own output port match (S22),
  and "Reverse isolation >60 dB" describes output-to-input leakage, neither
  of which is a load-mismatch damage rating. The full service manual
  (Keysight part 08347-90023) that might document this is gated behind a
  login and wasn't accessible. Decided to proceed with the -10 dBm
  threshold anyway without empirically fault-testing at reduced power
  first -- if the amplifier is later found to be damaged or behaving
  oddly, revisit this open question first.

## E4403B spectrum analyzer

- **Trace averaging** is `AVER:STATE ON` + `AVER:COUNT n`, not
  `DISP:WIND:TRAC1:MODE AVER` (undefined header on this firmware).
  `TRAC1:MODE` only accepts `WRITE|MAXHOLD|MINHOLD|VIEW|BLANK`.
- **`TRAC1:MODE BLANK` poisons subsequent reads**: `TRACE:DATA?` returns a
  flat sentinel (`400.0` everywhere) until you set the mode back to
  `WRITE`. Looks like a driver bug, is actually leftover instrument state.
- **Amplitude calibration can genuinely drift out of spec.** We hit a real
  fault where readings were 20-37 dB too high, worse at some frequencies
  than others. All of the instrument's own settings (attenuation, preamp,
  units, offset) checked out normal -- it was a real internal cal fault, not
  a settings mistake. **Fix: front panel Align Now -> RF (not Align Now ->
  All), with a cable connected to the input.** After a real cal fault, don't
  trust *any* absolute dBm reading until this has been done and reverified
  with a known source.
  **Reconfirmed, with the generator connected directly to the analyzer
  (known power in, no cable/amplifier/coupler in between):** the analyzer
  itself reported `SYST:ERR?` = `652, "Connect Calibration Output to Input"`
  on several unrelated commands (`FORM REAL,32`, `FREQ:CENT`, `FREQ:SPAN`)
  -- it's asking for its own internal alignment. Measured error is NOT a
  constant offset -- it grows with input power, i.e. this isn't only a
  calibration fault but likely front-end compression/overload stacked on
  top of it:

      set (dBm)   measured (dBm)   delta (dB)
        -40.0         -19.92          +20.08
        -30.0          -9.82          +20.18
        -20.0           0.11          +20.11
        -10.0          11.09          +21.09
         -5.0          26.55          +31.55
          0.0          36.51          +36.51

  Roughly constant ~+20 dB from -40 to -10 dBm, then jumps to +31.5 and
  +36.5 dB at -5 and 0 dBm.
  **This fault arose recently -- confirmed the earlier amplifier
  gain/max-output and resonance-sweep measurements were NOT affected by
  it** (taken before this developed). What it does explain: the 4th
  interlock test's immediate trip (`-17.07 dBm` displayed on the very
  first reading, no baseline period, no physical disturbance) was most
  likely a **false trip caused by this fault**, not real resonance drift as
  first guessed -- a true baseline around -40 dBm (consistent with the
  -42 to -50 dBm baselines seen in the earlier, uncompromised interlock
  tests) plus this fault's +20 dB offset would display right around -20
  dBm, over the -30 dBm threshold with no real cause. Re-verify with a
  fresh interlock test once the analyzer is realigned, rather than trusting
  that 4th test's "resonance drifted" explanation.
  **Resolved.** First `Align Now -> RF` attempt (with `AMPTD REF OUT`
  correctly cabled to `INPUT 50` Ohm) was run immediately after power-on
  and did NOT fix it -- `652` errors and the ~+20 dB fault persisted
  essentially unchanged. **The missing step was the ~5 minute warm-up**
  (the E4403B's own spec: meets spec "5 minutes after the analyzer is
  turned on, and after ALIGN NOW [RF] has been run" -- aligning cold
  doesn't count). After warming up and re-running the align: zero `652`
  errors, and the offset came back as a rock-solid constant -4.4 to -4.5 dB
  across the entire -40 to 0 dBm range tested -- exactly the healthy
  "residual cable loss" figure below, confirming the analyzer is fully
  healthy again. If this recurs, warm up for 5 min *before* aligning, not
  just before measuring.
- **Even when calibration is healthy, expect a small residual offset** from
  ordinary cable loss (we consistently see ~-4.4 to -4.5 dB direct
  generator-to-analyzer). This is normal, not a fault -- re-measure if the
  cable changes.
- **Noise floor is RBW/attenuation dependent, and auto-RBW isn't always what
  you expect.** Measured ~-64.3 dBm median at 1 MHz RBW / 10 dB attenuation,
  but the analyzer's auto-coupling picked 3 MHz RBW for the same 500 MHz
  span on one occasion, giving a very different-looking floor. Set `BAND`
  explicitly if you need a result comparable to a previous measurement.
- **"Query UNTERMINATED" / frozen-looking display**: caused by an
  exploratory SCPI query that isn't valid on this firmware timing out on
  the controller side without ever reading the response, leaving the
  instrument's output queue in a pending state. Fix: drain any stale
  response (`inst.read()` in a loop until it raises), then `inst.clear()`
  (GPIB device clear) followed by `*CLS`.

## NanoVNA-F V3 vector network analyzer

- **`recall {slot}` (e.g. `recall 0`) reliably crashed the USB-CDC connection
  on our unit** (firmware `0.6.0`, build Jun 18 2025): the device echoes the
  command, then the port goes completely unresponsive -- Windows reports
  "a device attached to the system is not functioning" on any further
  read/write or even just reconfiguring the port's timeout. This happened
  twice in a row under the same conditions. **A full power cycle (not just
  USB replug) was required to recover both times** -- unplugging/replugging
  the USB cable alone was not enough to bring the port back.
- **Confirmed this is a genuine firmware hang, not a clean USB reset**: after
  sending `recall 0`, polled Windows' USB enumeration (`vid=0x0483,
  pid=0x5740`) every 0.2s for 25s -- the device stayed listed/enumerated the
  entire time (never disappeared and re-enumerated), yet every attempt to
  actually communicate with it (even just opening a fresh serial handle)
  failed with "a device attached to the system is not functioning." That
  combination -- descriptor still registered, but the USB transfer layer
  dead -- points to the MCU's firmware locking up (e.g. in an interrupt
  handler or the main loop) rather than doing any kind of USB reset/reboot.
  Waiting longer or reconnecting differently does not help; this has now
  crashed 3 times, always needing the same physical power cycle. Likely
  needs a firmware fix on the NanoVNA side, not a driver-side workaround.
  Treat any `recall`/state-restore command as **crash-risk** until this
  firmware is updated/fixed, and don't call it from an unattended script
  without a human present to power-cycle if it hangs.
- The bare `cal` command (no arguments) also does not return to the `ch> `
  prompt in any reasonable time -- it appears to expect a further
  interactive step rather than just printing usage and returning like most
  other commands do here. Always pass a subcommand:
  `cal [load|open|short|thru|done|reset|on|off]` (note: `load` here is the
  *load standard* of an OSL cal, not "load a saved calibration" -- there is
  no such subcommand on `cal`).
- **Calibration and other instrument state save/recall is a separate
  command from `cal`**: `save {id}` / `recall {id}` persist/restore a full
  state slot (frequency plan + cal coefficients + display settings), not
  just the calibration coefficients alone.
- **Tried `reset` (full device reboot) as a `recall`-avoiding way to load a
  saved calibration** -- some docs for other NanoVNA firmware forks say
  `save 0` auto-restores at power-on, so a clean reboot should apply
  whatever's in slot 0 without ever touching the buggy `recall` path.
  **Verdict: not reliable enough to use.** Across 3 attempts: 1 self-recovered
  cleanly within ~25s; 2 got stuck with the port still listed in Windows'
  device list (`vid=0x0483, pid=0x5740`) but never actually openable --
  one of those needed only a USB replug, the other needed a full power
  cycle even though the device's own screen looked normal/responsive the
  whole time. That's a 2-in-3 rate of needing physical intervention --
  meaningfully less catastrophic-looking than `recall`'s 100% hard hang,
  but not meaningfully safer to actually rely on. **Conclusion: there is no
  known reliable way to (re)load a saved calibration on this unit without
  physical intervention.** For now, treat calibration as something you set
  once per session from the front panel (or accept running uncalibrated,
  as `nanovna.py` currently does) rather than something a script loads
  automatically -- don't add a `reset`-based `load_calibration()` path
  without addressing this reliability problem first.
- **The real fix is almost certainly to stop trying to use the device's
  `cal`/`save`/`recall` state machine at all, and calibrate on the host
  instead -- this is what NanoVNA-Saver itself does.** Checked its source
  (`Calibration.py`, `Windows/CalibrationSettings.py`): it measures OPEN/
  SHORT/LOAD standards via ordinary sweeps (the same `sweep`/`data 0`
  commands we already use -- no special device-side "cal open" state is
  involved), computes the standard vector error-correction terms
  (directivity/port-match/tracking, the classic 3-term one-port OSL model)
  entirely in Python, applies that correction to data after reading it, and
  saves/loads the calibration as a plain file on the PC's disk -- never the
  device's internal flash slots. Their own code comment on the manual
  cal-standard buttons says outright: "The buttons do not sweep for you nor
  do they interact with the NanoVNA calibration... If you are trying to do
  a calibration of the NanoVNA, do so on the device itself instead" -- i.e.
  even NanoVNA-Saver's authors treat the device's own `cal`/`recall`
  mechanism as something for the front panel, not for scripting.
  **Not implemented yet** -- `nanovna.py` still runs uncalibrated. When we
  do this, it should be a from-scratch one-port OSL calibration routine in
  `nanovna.py` (sweep with OPEN/SHORT/LOAD connected in turn, compute the
  3-term correction, apply to subsequent sweeps), entirely independent of
  the crash-prone `recall`/`reset`/`cal` device commands above.
- `nanovna.py`'s `exec_command()` (borrowed from NanoVNA-Saver) assumes
  every command eventually re-emits a `ch> ` prompt line. Both gotchas
  above break that assumption -- a command that never returns to the
  prompt will spin through all its retries and then raise `IOError`, but by
  then the underlying pyserial `readline()` calls may have already been
  blocking far longer than `max_retries * wait` would suggest, since a wedged
  USB-CDC device can make Windows serial reads hang past their nominal
  timeout.

## RTB2004 oscilloscope

- **`ACQuire:SRATe?`'s relationship to the real per-sample spacing depends on
  acquisition mode/point count/channel count -- don't assume a fixed
  correction factor.** An earlier `make_t()` divided the reported rate by 4;
  that was apparently right for whatever settings it was written against,
  but is wrong under `rtb2004.py`'s actual settings (`ACQuire:MEMory MANual`
  + `ACQuire:POINts` + segmented mode). Verified directly against a known
  80 MHz reference signal (`rtb2004_timebase_check.ipynb`): using the
  reported rate as-is gives the correct frequency; dividing by 4 does not.
- **`CHANnel<n>:DATA?` (with `DATA:POINts MAX`) returns a wider buffer than
  what's shown on the display -- don't derive the time axis from
  `TIMebase:POSition`/`TIMebase:RANGe`, they describe the display, not the
  returned array.** With `set_timebase()`'s `TIMebase:POSition 3e-6` and
  `ACQuire:POINts 10000`, `TIMebase:RANGe?` reports `1.2e-6` -- that's the
  *displayed graticule*, i.e. what you'd see on the physical screen or
  measure with the front-panel cursors, and `POSition - RANGe/2 = 2.4e-6`
  correctly gives *that* window's start. But `ACQuire:MEMory MANual` with
  `POINts=10000` acquires a much deeper buffer than the 3000 samples (at
  2.5 GSa/s) the display needs for its 1.2 us window -- the other 7000
  samples (3500 before + 3500 after, symmetric because `TIMebase:REFerence`
  is 50%) are captured too, so you can pan/zoom the display after a single
  trigger without re-acquiring. `CHANnel<n>:DATA?` with `DATA:POINts MAX`
  returns that whole 10000-sample buffer, not just the displayed 3000 --
  confirmed by directly counting: exactly 3500 samples in the returned
  array fall before the display's nominal start and 3500 after its end.
  So the buffer's start (`CHANnel<n>:DATA:XORigin?` = `1.0e-6`) is real and
  correct for the array you actually get back in Python -- it's just
  answering a different question than "where does the display start."
  Always get the time axis from `CHANnel<n>:DATA:XORigin?` /
  `CHANnel<n>:DATA:XINCrement?` right after reading out a waveform
  (`RTB2004.get_time_origin()`) and feed that into `make_t(..., t0_s=...)`
  -- never from the timebase/display settings, which describe a different
  (narrower) window than what you're processing.
- **The exact relationship, if you need to predict it without querying**
  (verified against 5 independent `(points, position, scale)` configurations,
  exact match every time, including cases where the buffer starts before
  the trigger and `XOrigin` comes out negative):

      XOrigin = TIMebase:POSition - num_points / (2 * sample_rate)
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

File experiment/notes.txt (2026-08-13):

- why not esr?
    - can't really measure resonator without diamond now

- background
    - not when generator is not on, but TTL on
    - not when amplifier is not on but other things on
    - not when amplifier goes directly into the load
        - or when amplifier goes through isolator and coupler but not into resonator
    - still there when input to the PMT is blocked
        - still there w/o the PMT being powered
    - turned off amplifier to pmt: not there

- preamp closer: more background
- switched to resistor 500 ohm for slower cw odmr

- maybe we cannot see the signal but it is there
    - average more to see it
- maybe it is just not there at all, anywhere
    - later, maybe sand down the resonator, decrease the laser intensity even more?
- maybe it is there but shifted in frequency
    - tune it a bit later tonight

1kohm, no nd filter for now
- for a while it was useless data because not aligned

- 80 mhz was never on, for lockin before scan/

- everything before rabi6 was taken with 1kOhm

- rabi also lock in signal at way off NV resonance
- blocked path to PMT: no lock-in signal anymore
- still shows up when directly into load
- still shows up when switch is just not powered
- still shows up when rf is completely off
- still shows up when two power supplies completely off
- don't show up when the rf for aom turned off
- shows up even when ch2 is hold constant
- don't show up when ch1 hold constant
- why decay?
    - external trigger constant
        - instead of decay wildly oscillating
- no internal repeat => still signal
    - no wait for trigger => no signal

to run cw odmr: 
python cw_odmr_lock_in.py run rabi_new_scan threshold_dbm=-5 coil_current_a=2 freq_step_hz=200e3
don't forget ref for lockin comes from ch2, not sync

python rabi.py run rabi_new4_fix_trigger threshold_dbm=-5 freq_hz=2.844e9 mw_start_us=0.02 mw_stop_us=1 mw_step_us=0.01 fine_sweep=false

python rabi.py run-repeat measurement14 n_repeats=5 freq_hz=2.842e9 threshold_dbm=-5 use_resonance_freq=true coil_scan_start_a=1.0 coil_scan_stop_a=4.0 coil_scan_step_a=0.1 coil_scan_tau_mw_us=0.5 coil_scan_n_repeats=20 fixed_sensitivity=true sensitivity_v=1e-4 mw_start_us=0.005 mw_stop_us=1 mw_step_us=0.05 extra_settle_s=1
[rabi] repeat 1/5: running measurement14_repeat0 (saved into measurement14/)

python rabi.py run-repeat measurement17 laser_us=5 constant_shot_period=true pad_min_us=0.1 n_repeats=5 freq_hz=2.842e9 threshold_dbm=-5 use_resonance_freq=true coil_scan_start_a=1.0 coil_scan_stop_a=5.0 coil_scan_step_a=0.1 coil_scan_tau_mw_us=0.5 coil_scan_n_repeats=5 mw_start_us=0.005 mw_stop_us=0.5 mw_step_us=0.01 extra_settle_s=1

python pulsed_odmr.py run-repeat tau_scan_14 tau_mw_us_list=0.13,0.16,0.19 n_repeats=1 use_resonance_sweep=false start_hz=2.855e9 stop_hz=2.885e9 freq_step_hz=50e3 threshold_dbm=-5 laser_us=5 extra_settle_s=1 coil_current_a=0 anchor_free_reps=800000 drive_power_dbm_list=-25

python rabi.py run-repeat measurement17 laser_us=5 constant_shot_period=true pad_min_us=0.1 n_repeats=5 freq_hz=2.84e9 threshold_dbm=-5 coil_current_a=2.5 mw_start_us=0.02 mw_stop_us=5 mw_step_us=0.2 extra_settle_s=1

python pulsed_odmr.py run-repeat scan1 tau_mw_us_list=0.5,1.0,2.0,5.0 n_repeats=5 freq_hz=2.8e9

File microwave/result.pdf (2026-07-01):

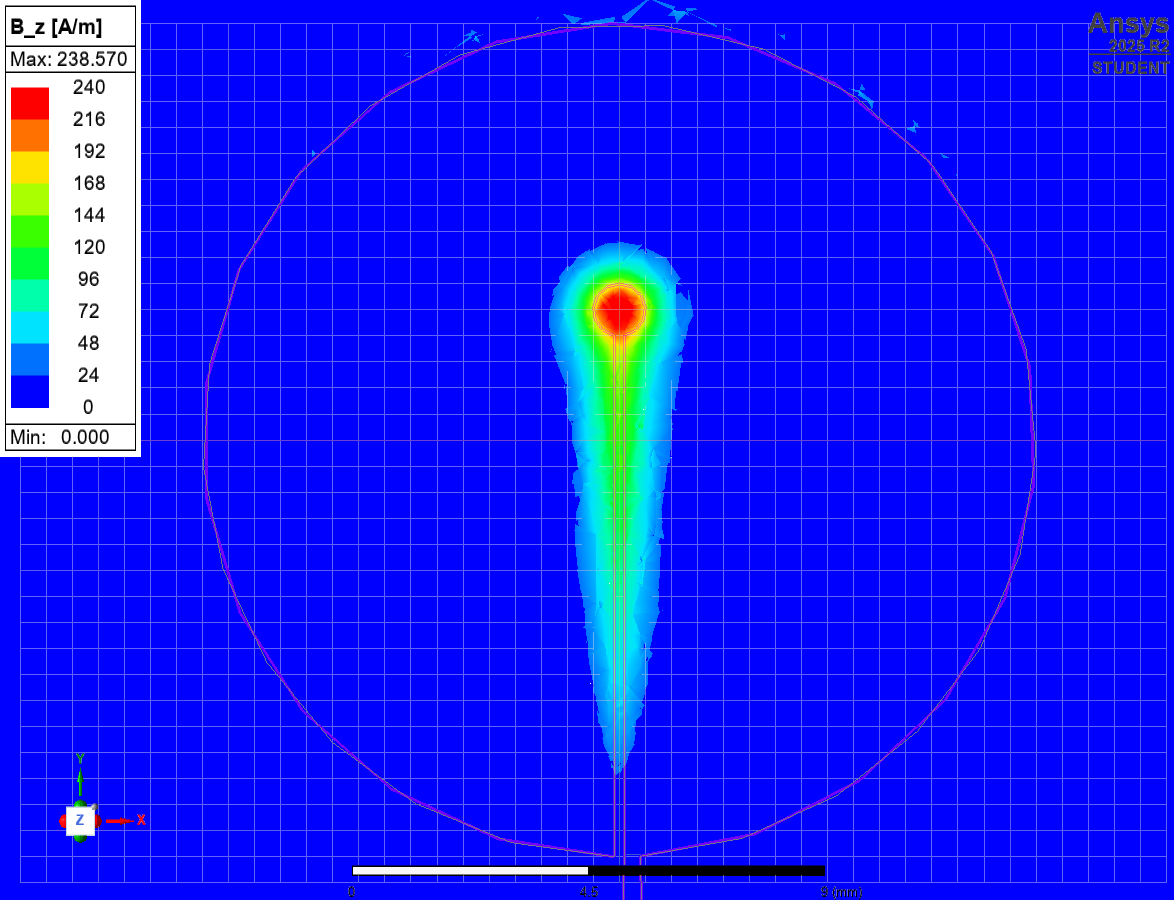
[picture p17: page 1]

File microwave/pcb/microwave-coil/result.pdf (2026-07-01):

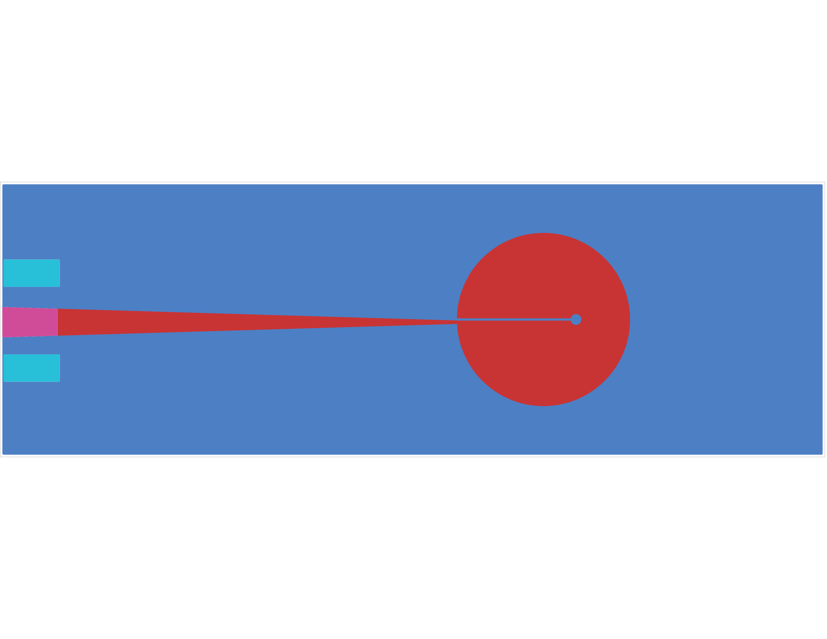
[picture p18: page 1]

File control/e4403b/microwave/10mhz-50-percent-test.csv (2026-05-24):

frequency_hz | amplitude_dbm
2.550000000000000000e+09 | -5.694200134277343750e+01
2.551250000000000000e+09 | -5.666400146484375000e+01
2.552500000000000000e+09 | -6.020000076293945312e+01
2.553750000000000000e+09 | -6.116699981689453125e+01
2.555000000000000000e+09 | -6.147999954223632812e+01
2.556250000000000000e+09 | -6.014599990844726562e+01
2.557500000000000000e+09 | -6.123300170898437500e+01
2.558750000000000000e+09 | -6.024800109863281250e+01
2.560000000000000000e+09 | -5.720399856567382812e+01
2.561250000000000000e+09 | -5.852600097656250000e+01
2.562500000000000000e+09 | -5.963600158691406250e+01
2.563750000000000000e+09 | -6.104100036621093750e+01
2.565000000000000000e+09 | -6.027600097656250000e+01
2.566250000000000000e+09 | -6.104700088500976562e+01
2.567500000000000000e+09 | -6.081600189208984375e+01
2.568750000000000000e+09 | -5.933000183105468750e+01
2.570000000000000000e+09 | -5.857600021362304688e+01
2.571250000000000000e+09 | -5.843199920654296875e+01
2.572500000000000000e+09 | -5.803699874877929688e+01
2.573750000000000000e+09 | -6.120299911499023438e+01
2.575000000000000000e+09 | -6.019800186157226562e+01
2.576250000000000000e+09 | -6.049000167846679688e+01
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

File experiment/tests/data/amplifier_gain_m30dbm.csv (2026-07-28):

frequency_hz | output_power_dbm | gain_db
2.000000000000000000e+09 | -1.276500000000000057e+01 | 1.723499999999999943e+01
2.005000000000000000e+09 | -1.262100000000000044e+01 | 1.737899999999999778e+01
2.010000000000000000e+09 | -1.236200000000000010e+01 | 1.763799999999999812e+01
2.015000000000000000e+09 | -1.202399999999999913e+01 | 1.797599999999999909e+01
2.020000000000000000e+09 | -1.163599999999999923e+01 | 1.836400000000000077e+01
2.025000000000000000e+09 | -1.122100000000000009e+01 | 1.877899999999999991e+01
2.030000000000000000e+09 | -1.095400000000000063e+01 | 1.904599999999999937e+01
2.035000000000000000e+09 | -1.075600000000000023e+01 | 1.924399999999999977e+01
2.040000000000000000e+09 | -1.064000000000000057e+01 | 1.935999999999999943e+01
2.045000000000000000e+09 | -1.037299999999999933e+01 | 1.962700000000000244e+01
2.050000000000000000e+09 | -1.070500000000000007e+01 | 1.929500000000000171e+01
2.055000000000000000e+09 | -9.470000000000000639e+00 | 2.053000000000000114e+01
2.060000000000000000e+09 | -8.977999999999999758e+00 | 2.102199999999999847e+01
2.065000000000000000e+09 | -8.542999999999999261e+00 | 2.145700000000000074e+01
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

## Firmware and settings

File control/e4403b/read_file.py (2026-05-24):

import pyvisa
import time
from pathlib import Path
import numpy as np
import sys


rm = pyvisa.ResourceManager()
instr = rm.open_resource('GPIB0::18::INSTR')

instr.timeout = 20000
instr.write_termination = '\n'
instr.read_termination = '\n'

instr.write(":FREQ:CENT 2.8GHz")
instr.write(":FREQ:SPAN 500MHz")

instr.write(":FORM REAL,32")          # binary float transfer
instr.write(":FORM:BORD SWAP")        # little-endian

instr.write(":DISP:WIND:TRAC1:MODE AVER")
instr.write(":AVER:COUNT 20")
instr.write(":INIT:CONT OFF")

for _ in range(20):
    instr.write(":INIT:IMM")
    instr.query("*OPC?")

# instr.write(":DISP:WIND:TRAC1:MODE MAXH")
# for _ in range(20):
#     instr.write(":INIT:IMM")
#     instr.query("*OPC?")

# # Trigger sweep
# instr.write(":INIT:IMM")
# instr.query("*OPC?")                  # wait until sweep completes

trace = instr.query_binary_values(
    ":TRACE:DATA? TRACE1",
    datatype='f',
    is_big_endian=False
)

trace = np.array(trace)

print("Trace points:", len(trace))

center = float(instr.query(":FREQ:CENT?"))
span = float(instr.query(":FREQ:SPAN?"))

start_freq = center - span / 2
stop_freq  = center + span / 2

freqs = np.linspace(start_freq, stop_freq, len(trace))

save_dir = Path("./microwave")
save_dir.mkdir(exist_ok=True)

if len(sys.argv) > 1:
    filename = sys.argv[1]
else:
    filename = "esa_trace.csv"

filepath = save_dir / filename

data = np.column_stack((freqs, trace))

np.savetxt(
    filepath,
    data,
    delimiter=",",
    header="frequency_hz,amplitude_dbm",
    comments=""
)

print(f"Saved trace to: {filepath}")

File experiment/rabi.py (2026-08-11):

"""
rabi.py -- pulsed Rabi oscillation measurement: sweeps the microwave pulse
length (tau_mw) at a FIXED, known ODMR resonance frequency, reading out via
lock-in synchronous detection against a slow block-chopped reference
(n_reps loop iterations with the MW pulse present, then n_reps without),
instead of cw_odmr_lock_in.py's continuous fast chop.

AWG sequence upload (setup_awg_sequences() below) mirrors what was verified
on real hardware in tests/rabi_awg_marker_test.ipynb -- see notes.md's
"Rabi oscillation" section for the full debugging history. Key points:

- The lock-in reference marker lives on CH2's own DATA:SEQ sequence
  (highAtStart/lowAtStart on its mw-on/mw-off blocks), not CH1's -- there
  is only one physical Sync/Marker BNC, shared between channels and
  switched to CH2 via OUTPut:SYNC:SOURce, so the reference is correct
  regardless of any residual CH1/CH2 timing offset.
- CH1/CH2 relative timing (does the laser pulse land in the intended place
  relative to the MW pulse) is kept aligned using the Keysight manual's
  documented "start a sequence on a trigger" technique (p.181): a brief
  DC "anchor" segment marked "onceWaitTrig" at the front of each channel's
  sequence. Both channels hold at their anchor until a shared external
  trigger edge advances them together. This REQUIRES a second instrument
  (the Siglent SDG1062X, see SDG_RESOURCE) supplying a CONTINUOUS,
  sufficiently fast square wave into the AWG's rear-panel Ext Trig BNC --
  every full sequence loop wraps back to the anchor and needs a fresh
  trigger, so a one-time edge is not enough; the SDG1062X's frequency is
  reconfigured every sweep point since it must stay at or above the
  current point's own block-cycle rate (see _configure_external_trigger()).
  `PHASe:SYNChronize` and plain `TRIG:SOUR`/burst-mode approaches were all
  tried first and confirmed broken/inapplicable on this firmware -- see
  notes.md before reintroducing any of them.

See notes.md's "cw_odmr_lock_in.py operation notes" section for the
lock-in/PSU conventions reused here.

Interlock note: reflected power is checked with the spectrum analyzer in
MAX HOLD mode (HP8673H.read_max_hold_reflected_power_dbm()), not a single
sweep. A single sweep (read_reflected_power_dbm(), used everywhere else in
this codebase) has no way to reliably land inside a microsecond-scale MW
pulse -- GPIB round-trip time plus the analyzer's own sweep time both run
far slower than that. MAX HOLD instead free-runs for several full
reference periods, so it's guaranteed to catch at least one real pulse at
its peak somewhere in that window -- trading timing precision for a
hardware guarantee. Each check takes multiple reference periods to
complete, so it only runs periodically (interlock_check_interval), not on
every sweep point.

Usage:
    python rabi.py run <file_name> [key=value ...]
        Sweeps the MW pulse length across [mw_start_us, mw_stop_us],
        recording the SR830's X/Y at each point. See cmd_run()'s docstring
        for the full list of key=value overrides. Saves
        data/<file_name>/<file_name>_rabi_mw_us.npy, _rabi_x.npy,
        _rabi_y.npy, _rabi_reflected_dbm.npy, _rabi_ref_freq_hz.npy,
        _rabi_reference_unlock.npy, _rabi_metadata.txt.

    python rabi.py run-no-mw <file_name> [key=value ...]
        Crosstalk-isolation diagnostic -- a separate, self-contained sweep
        (same AWG sequences, same CH2 gate/switch toggling, same sweep)
        that never connects to or commands the generator, amplifier
        supply, or coil supply at all -- turn the generator's RF off/
        disconnect it, and power down both PSUs, yourself before running
        this. See cmd_run_no_mw()'s docstring for why (isolating whether a
        spurious off-resonance/no-MW-near-sample signal found on real
        hardware -- confirmed to persist even with RF off -- also depends
        on either PSU being powered). Confirmed on real hardware to
        persist with the generator's RF AND both PSUs off.

    python rabi.py run-ch2-constant <file_name> [key=value ...]
        Crosstalk-isolation diagnostic, second stage -- builds on
        run-no-mw (no generator, no interlock, no PSUs) and additionally
        holds CH2's own analog output physically constant (never
        switching) while its marker/reference still toggles normally. See
        cmd_run_ch2_constant()'s docstring for why (isolating whether the
        spurious signal needs CH2's analog output to actually switch, or
        only needs the marker/reference toggle). Confirmed on real
        hardware to persist even with CH2 held constant.

    python rabi.py run-ch1-ch2-constant <file_name> [key=value ...]
        Crosstalk-isolation diagnostic, third stage -- builds on
        run-ch2-constant and additionally holds CH1 constant too (a
        plain, non-sequenced continuous 80 MHz sine, no DATA:SEQ at all).
        See cmd_run_ch1_ch2_constant()'s docstring for why (isolating
        whether the spurious signal needs CH1's OWN sequence table to be
        advancing through segments, even ones with identical output, or
        only needs CH2's marker/reference toggling).

    python rabi.py calibrate-phase <file_name> [key=value ...]
        Runs continuously at a single, fixed tau_mw and calls the SR830's
        auto-phase (APHS) to null Y against the real reference -- phase_deg
        is NOT auto-calibrated by cmd_run() itself, so run this first and
        pass the result into cmd_run() via phase_deg=<value>. See
        cmd_calibrate_phase()'s docstring for key=value overrides.

Example:
    python rabi.py run rabi1 freq_hz=2.8692e9 mw_stop_us=4.0
    python rabi.py run-no-mw rabi_no_mw_test
    python rabi.py run-ch2-constant rabi_ch2_const_test
    python rabi.py run-ch1-ch2-constant rabi_ch1_ch2_const_test
    python rabi.py calibrate-phase phasecal1 mw_us=1.2
"""
import sys
import time

import numpy as np

import ks33600a
from hp8673h import HP8673H
from sr830 import SR830
from spd1305x import SPD1305X, voltage_for_current
from spd1168x import SPD1168X
from sdg1062x import SDG1062X
from cw_odmr import parse_kv_args, _tee_stdout
from cw_odmr_lock_in import set_switch_static

AWG_RESOURCE = "USB0::0x0957::0x5707::MY53800810::INSTR"
GEN_RESOURCE = "GPIB1::19::INSTR"
SA_RESOURCE = "GPIB0::18::INSTR"
SR830_RESOURCE = "GPIB2::2::INSTR"
# Siglent SDG1062X, driven by sdg1062x.py -- supplies the continuous
# external trigger the AWG's "onceWaitTrig" anchor segments need to keep
# CH1/CH2 aligned (see module docstring / notes.md). NOT used via its own
# run() method (that configures it to be externally triggered itself, the
# opposite of what's needed here) -- configured directly as a plain
# continuous square-wave source by _configure_external_trigger() below.
SDG_RESOURCE = "USB0::0xF4EC::0x1103::SDG1XDDX6R5043::INSTR"
# NOT YET VERIFIED -- confirm with pyvisa.ResourceManager().list_resources()
# before trusting this (see notes.md's GPIB-bus-numbering gotchas).
# SPD1305X driving the static-field coil (see spd1305x.py) -- chosen for
# this role over the SPD1168X for its higher current limit.
COIL_PSU_RESOURCE = "USB0::0xF4EC::0x1410::SPD13DCD7R1877::INSTR"
# SPD1168X driving the RF amplifier supply.
AMP_PSU_RESOURCE = "USB0::0xF4EC::0x1410::SPD13DCQ7R0986::INSTR"

DATA_DIR = "D:\\rabi"

RESEQUENCE_INTERVAL = 4  # reset the AWG this often to clear out accumulated
                          # DATA:SEQ sequences before hitting its "too many
                          # sequences defined" limit -- same lesson as
                          # t1_test.py's RESEQUENCE_INTERVAL. Lowered from 20
                          # now that each point's combined arb (n_reps copies
                          # of on/off baked into one waveform) is much larger,
                          # so resetting more often also keeps the AWG's arb
                          # waveform memory from accumulating/fragmenting
                          # across points, not just the sequence table.
                           # NOT yet re-validated against anchor_free_reps:
                           # each point's own sequence is now much larger
                           # (up to ~2*anchor_free_reps+1 listed segments,
                           # vs. 3 before), a DIFFERENT AWG resource (total
                           # listed segments within one sequence, see
                           # setup_awg_sequences()'s docstring) than the
                           # "too many sequences defined" limit this
                           # interval was tuned against (total DISTINCT
                           # sequence names accumulated). Watch for errors
                           # here on real hardware -- may need retuning.


def build_block_descriptor(sequence_name, segments):
    """Same DATA:SEQ block-descriptor builder as t1_test.py/pulsed_odmr.py."""
    parts = [f'"{sequence_name}"']
    for arb_name, repeat_count, play_control, marker_mode, marker_point in segments:
        parts.append(
            f'"{arb_name}",{repeat_count},{play_control},{marker_mode},{marker_point}'
        )
    payload = ",".join(parts)
    payload_bytes = payload.encode("utf-8")
    payload_len = len(payload_bytes)
    n = len(str(payload_len))
    return f"#{n}{payload_len}{payload}"


def _us_to_samples(duration_us, sample_rate_hz):
    return max(1, round(duration_us * 1e-6 * sample_rate_hz))


def _rf_pulse(freq_hz, n_samples, sample_rate_hz):
    t = np.arange(n_samples) / sample_rate_hz
    return np.sin(2 * np.pi * freq_hz * t).astype(np.float32)


def _const(n_samples, value):
    return np.full(n_samples, value, dtype=np.float32)


ANCHOR_SAMPLES = 32  # minimum DATA:SEQ segment length on the 33600 Series


def setup_awg_sequences(awg, mw_us, n_reps, laser_us, pre_us, post_us,
                         sequence_name_ch1, sequence_name_ch2,
                         ch1_vpp=0.632, ch2_vpp=5.0, ch2_offset_v=2.5,
                         sample_rate_hz=1e9, ch2_hold_constant=False,
                         ch1_hold_constant=False, anchor_free_reps=1,
                         pad_us=0.0):
    """
    Uploads CH1's laser-pulse-train arb and CH2's mw-on/mw-off gate arbs
    for one rep at the current mw_us, then builds and uploads a DATA:SEQ
    sequence per channel, and configures both channels' output. Verified
    on real hardware in tests/rabi_awg_marker_test.ipynb -- see notes.md's
    "Rabi oscillation" section for the debugging history behind every
    choice below.

    ch2_hold_constant=True (crosstalk-isolation diagnostic, see notes.md's
    "spurious off-resonance/no-MW-near-sample signal" entry and
    cmd_run_ch2_constant()'s docstring): the marker (asserted/negated via
    "highAtStartGoLow", which is what the lock-in's reference is actually
    derived from via OUTPut:SYNC:SOURce CH2) and CH2's own ANALOG output
    value are independent attributes of a DATA:SEQ segment -- normally
    they change together (the combined arb's on-half uses gate_on_rep's
    real gate content, off-half uses gate_off_rep), but they don't have
    to. With this on, the arb's "on" half is built from gate_off_rep's
    content too (constant, physically off -- normalized -1.0, i.e. 0V
    once ch2_offset_v is applied) while the marker still asserts/negates
    at the same marker_point -- so CH2's real analog output voltage never
    actually changes at all (no physical switching happens downstream),
    but the lock-in still receives an identical, correctly-toggling
    reference. Isolates whether a spurious signal genuinely requires
    CH2's own analog output to physically switch, or only requires the
    marker/sync output to toggle (which alone would point at the marker/
    Sync BNC circuitry specifically, not CH2's analog DAC/switch-driving
    output).

    anchor_free_reps (applies to BOTH channels, regardless of
    ch2_hold_constant/ch1_hold_constant -- see notes.md's "spurious
    off-resonance/no-MW-near-sample signal" entry for the full history):
    each onceWaitTrig anchor's own LEVEL isn't the concern -- CH1's
    anchor (0.0) matches its own real "off" gap value, and CH2's anchor
    (-1.0) matches gate_off_rep's value. The concern is the trigger-wait
    DEAD TIME itself: every time a sequence wraps back through its
    anchor, it sits there for a small, asynchronous delay before the next
    external trigger edge arrives, delaying exactly when the next cycle's
    real content resumes -- a real, reproducible glitch landing at the
    SAME point in every cycle (see cmd_run_ch2_constant()'s docstring for
    how this was isolated on real hardware). anchor_free_reps sets how
    many full off+on (or 2*n_reps-rep, for CH1) cycles play as ONE
    combined, pre-baked arb before wrapping back to the anchor -- CH1 and
    CH2 MUST use the same value and wrap together (confirmed on real
    hardware that applying it to only one channel visibly misaligns them,
    CH1's pulses drifting relative to the Sync/marker output). Each
    channel's combined arb is listed exactly ONCE with repeat_count=
    anchor_free_reps -- a SINGLE table entry regardless of how large
    anchor_free_reps is (repeat count is free, like n_reps already is),
    unlike an earlier version of this that listed anchor_free_reps
    separate off+on/rep PAIRS (2*anchor_free_reps table entries), which
    hit a real ~250-listing AWG sequence-table ceiling on real hardware.
    The tradeoff moved from table-entry count to waveform memory/upload
    time instead: the combined arb is n_reps times bigger than a single
    rep -- confirmed working on real hardware up to n_reps=500 (see
    tests/rabi_combined_arb_marker_test.ipynb).

    ch1_hold_constant=True (paired crosstalk-isolation diagnostic, see
    cmd_run_ch1_ch2_constant()'s docstring): configures CH1 as a plain,
    non-sequenced continuous FUNC SIN at 80 MHz / ch1_vpp instead of
    building/uploading its own DATA:SEQ sequence at all -- no "anchor"/
    "ch1_combined" arbs, no onceWaitTrig, no external-trigger dependency
    for CH1. With ch1_hold_constant on, CH1 is fully decoupled from the
    block structure -- if ch2_hold_constant is also on, the ONLY thing
    left anywhere in the AWG still synchronous with the block reference
    is CH2's marker.

    pad_us (default 0.0, no effect): extra "off" dead time appended to the
    END of every rep (after post_us), on BOTH channels, before the next
    rep starts -- lets a caller (cmd_run()'s constant_shot_period) hold
    the TOTAL rep period (and therefore the reference frequency and the
    laser's duty cycle) IDENTICAL across an entire tau_mw sweep by
    compensating for the varying mw_us: pad_us = (mw_max_us - mw_us) +
    pad_min_us, so laser_us+pre_us+mw_us+post_us+pad_us is the same
    constant at every point regardless of mw_us. 0.0 (skips adding the
    segment at all, not just a zero-length one) reproduces the exact
    sample counts this function has always produced.

    REVERTED an attempted split (configure_awg_outputs() called once,
    output-stage config removed from here) that was meant to cut down on
    suspected relay wear from reissuing VOLT/OUTP:LOAD/OUTPUT ON/etc every
    sweep point -- on real hardware this did NOT reduce clicking and the
    resulting sequence/waveforms looked wrong, so it's reverted back to
    reconfiguring the full output stage every call, matching the last
    confirmed-working behavior. See notes.md for the (now retracted) theory
    and this revert.

    CH1: "ch1_combined" -- 2*n_reps copies of a bright laser pulse
    (laser_us) followed by a flat dark gap (pre_us + mw_us + post_us),
    concatenated into one arb -- CH1 doesn't care about the MW pulse's
    internal position or which half of the cycle is "on" vs. "off", just
    the total gap length, so it's the same content repeated throughout.

    CH2: "ch2_combined" -- gate_on_rep's content (high for mw_us, low for
    laser_us+pre_us+post_us) repeated n_reps times, followed by
    gate_off_rep's content (low for the entire rep) repeated n_reps times,
    concatenated into ONE arb. Each underlying rep has the SAME sample
    count as CH1's rep content (checked with an assert) so the two
    channels' blocks don't drift out of step.

    Both channels' sequences start with a brief "anchor" segment
    (ANCHOR_SAMPLES, "onceWaitTrig") before the real content -- the
    manual's documented "start a sequence on a trigger" technique
    (p.181). Each channel's anchor sits at THAT channel's own real
    "off"/rest level (0.0 normalized for CH1's 0-centered VOLTage
    convention, -1.0 normalized for CH2's unipolar 0-ch2_vpp mapping) --
    reusing one generic anchor value across both channels produces a
    brief wrong-level glitch on whichever channel doesn't use a 0-centered
    convention (confirmed on real hardware for CH2).

    The lock-in reference marker lives on CH2's sequence -- the
    "ch2_combined" listing is marked "highAtStartGoLow" (assert the
    marker high at the start of the segment, negate it low at
    marker_point, the sample index where the arb's on-content ends and
    off-content begins) -- OUTPut:SYNC:SOURce is set to CH2 here so the
    shared Sync/Marker BNC reflects it, independent of CH1/CH2 relative
    timing. Confirmed on real hardware that "highAtStartGoLow" re-fires
    on EVERY repeat of the segment, not just once across the whole
    anchor_free_reps-repeat block (see tests/rabi_combined_arb_marker_
    test.ipynb) -- this is what makes collapsing to one listing per
    channel actually give the same alternating reference as before.

    Clears both channels' volatile arb memory first: DATA:ARBitrary errors
    if an arb name already exists, and upload_waveform() doesn't check for
    that error (see notes.md), so reusing the same arb names across sweep
    points without clearing would silently leave stale data in place.

    sequence_name_ch1/sequence_name_ch2 must be unique per distinct mw_us
    used since the AWG's sequence table was last cleared (see
    RESEQUENCE_INTERVAL) -- re-uploading a DATA:SEQ under an already-used
    name does not actually replace it (see notes.md / t1_test.py's
    upload_sequence() docstring).

    Both channels are set to TRIG:SOUR EXT -- this requires a continuous
    external trigger on the AWG's rear-panel Ext Trig BNC to ever actually
    play (see _configure_external_trigger()/cmd_run()'s SDG1062X setup);
    without it, both channels sit forever at their anchor outputting
    nothing.
    """
    # Stop whatever sequence is currently playing before clearing/
    # reuploading arb memory. Previously relied on DATA:VOL:CLE alone to
    # safely replace an actively-playing arb -- worked in practice, but
    # with anchor_free_reps now often long enough that a point's sequence
    # is still mid-cycle (not idled back at its anchor) when we move to
    # the next point (see notes.md), abort first so the old sequence is
    # actually stopped rather than implicitly cut off by the clear.
    awg.write("ABOR")
    # NOTE: forcing TRIG1/2:SOUR through an IMM->EXT transition here (on
    # the theory that *RST's benefit was incidentally flushing a stale
    # trigger edge via that transition) was tried and DID NOT fix it --
    # rabi_new20_test still hit the same ~1.3-1.5e-4 rail at 2 of 6 points
    # with the toggle in place. That theory is falsified; see notes.md.
    awg.write("SOUR1:DATA:VOL:CLE")
    awg.write("SOUR2:DATA:VOL:CLE")

    laser_samples = _us_to_samples(laser_us, sample_rate_hz)
    pre_samples = _us_to_samples(pre_us, sample_rate_hz)
    mw_samples = _us_to_samples(mw_us, sample_rate_hz)
    post_samples = _us_to_samples(post_us, sample_rate_hz)
    # 0 (not _us_to_samples(0, ...), which would still return 1 -- see its
    # own "max(1, ...)" floor) so pad_us=0.0 reproduces the exact sample
    # counts this function has always produced, with no extra segment at
    # all.
    pad_samples = _us_to_samples(pad_us, sample_rate_hz) if pad_us > 0 else 0

    gate_on_rep_segments = [
        _const(laser_samples + pre_samples, -1.0),
        _const(mw_samples, 1.0),
        _const(post_samples, -1.0),
    ]
    if pad_samples > 0:
        gate_on_rep_segments.append(_const(pad_samples, -1.0))
    gate_on_rep = np.concatenate(gate_on_rep_segments)
    gate_off_rep = _const(
        laser_samples + pre_samples + mw_samples + post_samples + pad_samples, -1.0)

    if not ch1_hold_constant:
        ch1_rep_segments = [
            _rf_pulse(80e6, laser_samples, sample_rate_hz),
            _const(pre_samples + mw_samples + post_samples, 0.0),
        ]
        if pad_samples > 0:
            ch1_rep_segments.append(_const(pad_samples, 0.0))
        ch1_rep = np.concatenate(ch1_rep_segments)
        assert len(ch1_rep) == len(gate_on_rep) == len(gate_off_rep), (
            "CH1 and CH2 rep arbs must have identical sample counts, or the "
            "two channels' blocks will drift out of step"
        )
        anchor_ch1 = _const(ANCHOR_SAMPLES, 0.0)
        awg.upload_waveform(anchor_ch1, arb_name="anchor", ch=1, sample_rate=sample_rate_hz)
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

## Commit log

2026-04-16 Add files via upload
    For low laser power, the equations produce similar results to the measured photon count in this paper https://journals.aps.org/prb/abstract/10.1103/PhysRevB.85.121202, figure 2 (d). However, if we're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
    [plot-data.csv]
2026-04-17 Add files via upload
    Added darkroom photon count and darkroom measured voltage. Included the absorbance spectrum of the filter used to make darkroom measurements. Spectrum was taken on a CCS100 otpical spectrometer.
2026-05-05 save results
    [0000223.x_b]
2026-05-05 save version with resist
2026-05-06 save working solution for our physical setup
    [0000223.x_b]
2026-05-06 save without filled zone
    [microwave-coil.kicad_pcb, microwave-coil.kicad_sch]
2026-05-06 save new version
    [microwave-coil-2.kicad_pcb, microwave-coil.kicad_pcb]
2026-05-08 Filter Spectra
    FESH0800 is the serial number for the shortpass.
2026-05-16 rename folders
    [microwave-coil-2-B_Cu.gbr, microwave-coil-2-B_Mask.gbr, microwave-coil-2-B_Paste.gbr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]
2026-05-16 finish renaming
    [microwave-coil-2-B_Cu.gbr, microwave-coil-2-B_Mask.gbr, microwave-coil-2-B_Paste.gbr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]
2026-05-18 save data from microwave spectrum analyzer, edit code to plot spectra
    [0dbm_10_percent.csv, 10dbm_10_percent.csv, 10dbm_10_percent_1mhz_1.csv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]
2026-05-23 save work on experiment control
    [test.csv]
2026-05-24 sdg basically working
    [sdg1062x.csv, test.csv]
2026-05-24 save data on microwave pulses
    [100mhz-50-percent.csv, 10mhz-30-percent.csv, 10mhz-50-percent-test.csv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]
2026-05-28 freq test passed, add sample data
    [WFM01.CSV, WFM010.CSV, WFM011.CSV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]
2026-05-29 Voltage visualization at end
    Using the test_scope.csv waveform.
2026-05-30 save fixed generator
    [WFM01.CSV, WFM010.CSV, WFM011.CSV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]
2026-05-31 Coil control class added
    coil data included for regressions to esimtated gauss for currents we didn't measure.
    [X.xlsx, Y.xlsx, Z.xlsx]
2026-06-02 make t1 test work
    [dark.csv, polarization.csv, readout.csv]
2026-06-03 save data collection changes
    [dark.csv]
2026-06-04 Requested Cads
    [CopperTubeMount.stl, Helmholtz Coils.stl]
2026-06-23 Kasa Control Class
    for remote power control. Didn't include time keeping since we can do that in the main experimental control file. Documentation for the control class is here: https://github.com/python-kasa/python-kasa.
    [kasa_control.py]
2026-07-01 save before delete
    [simulated-s11.csv, wave-port.csv]
2026-07-25 microwave work, gave up on 2nd pcb because can't get rogers substrate, used lgr instead
    [lumped-port.csv, wave-port.csv]
2026-07-25 save microwave control
    [forward_power_sweep_2-3GHz_1MHz.csv, frequency_sweep_2.5-3.0GHz_1MHz.csv, full_trace_sweep_2.5-3.0GHz_100MHz-steps.csv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]
2026-07-25 save invalid data not connected to spectrum analyzer
    [coupler_terminated_reflected_2-3GHz_1MHz.csv, coupler_terminated_reflected_2-3GHz_1MHz_oldload.csv, isolator_no_load_reflected_2-3GHz_1MHz.csv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]
2026-07-25 isolator checked
    [coupler_terminated_reflected_2-3GHz_1MHz.csv, coupler_terminated_reflected_2-3GHz_1MHz_oldload.csv, forward_power_sweep_2-3GHz_1MHz.csv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]
2026-07-26 Tested with new power supply
2026-07-26 resonance working
    [resonance_150pt_2-3GHz_0dBm.csv, resonance_2.35-2.45GHz_settled.csv, resonance_2.4-2.6GHz_200kHz.csv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]
2026-07-26 start experiment scripts
    [X.csv, Y.csv, Z.csv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]
2026-07-26 save new sweep
    [reflected_no_isolator_open_2-3GHz_1MHz.csv, reflected_no_isolator_open_2-3GHz_1MHz_precal.csv, reflected_terminated_50ohm_2-3GHz_1MHz.csv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]
2026-07-28 save experiment code
    [amplifier_gain_m30dbm.csv, resonance_m40dbm_fine.csv]
2026-07-30 save switch
2026-07-31 save cleaned up data folder
    [amplifier_max_output_0dbm.csv, generator_direct_m20dbm.csv, new_amplifier_gain_m40dbm.csv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]
2026-08-03 save drawings
    [coil-holder.SLDPRT, copper-tube-mount.STEP, copper-tube.SLDPRT]
2026-08-06 move around files
    [amplifier_gain_m30dbm.csv, amplifier_max_output_0dbm.csv, generator_direct_m20dbm.csv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]
2026-08-12 power analysis
2026-08-12 old scope data
    [amp-20-mhz.CSV, amp-full-bandwidth.CSV, diff-setup-20-mhz-amp.CSV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]
2026-08-15 pulse tests
    [new_amplifier_power_scan_0dBm.csv, new_amplifier_power_scan_m10dBm.csv, new_amplifier_power_scan_m15dBm.csv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]
